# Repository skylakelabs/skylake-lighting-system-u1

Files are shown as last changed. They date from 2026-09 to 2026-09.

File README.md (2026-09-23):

# Skylake Lighting System for Snapmaker U1

Tested WLED integration for the Skylake LED Top Panel Kit. The stock U1 cavity-light control remains the master switch: off turns WLED off, and on loads WLED preset 1.

This README is the abbreviated procedure for users already comfortable with Fluidd and Klipper configuration. The complete hardware and beginner-focused walkthrough is maintained on the Skylake website.

> [!WARNING]
> This configuration transfers MCU pin `PE15` from the stock purifier to `skylake_24v`. Never let both objects own `PE15`. Back up `printer.cfg` and `moonraker.conf`, make no wiring changes while powered, and do not perform this work during a print.

## Files

| File | Purpose |
| --- | --- |
| [`skylake-wled.cfg`](skylake-wled.cfg) | Enables the top-cover 24 V rail and mirrors the cavity-light state to WLED. |
| [`skylake-moonraker.conf`](skylake-moonraker.conf) | Defines the WLED connection, preset, and 20-LED chain. |
| [`LEDTopPanel-SkylakeLabs-1.7.6.3mf`](models/LEDTopPanel-SkylakeLabs-1.7.6.3mf) | Prepared three-plate project with Snapmaker U1 slicer and support settings. |
| [`SnapmakerU1-LEDTopPanel1.7.6.stl`](models/SnapmakerU1-LEDTopPanel1.7.6.stl) | Raw model geometry for users who prefer to configure slicing manually. |

## Model files

For the recommended print setup, open the 3MF project in a compatible slicer and review its plate, material, and support settings before printing. Use the STL when importing the geometry into another slicer or creating a custom print profile.

Both model files are version **1.7.6** and are stored in the [`models`](models) folder.

## Advanced installation

1. On the U1 touchscreen, enable **Settings → Maintenance → Advanced Mode**. Open Fluidd and back up `printer.cfg` and `moonraker.conf`.
2. Upload `skylake-wled.cfg` and `skylake-moonraker.conf` beside the stock configuration files.
3. In `skylake-moonraker.conf`, replace the example `address` with the WLED controller's fixed IP address. Keep the supplied LED count:

   ```ini
   [wled skylake_lights]
   type: http
   address: 192.168.0.123
   initial_preset: 1
   chain_count: 20
   ```

4. In the stock `[purifier]` section of `printer.cfg`, comment out only the `PE15` assignment:

   ```ini
   [purifier]
   exhaust_pin: !PA8
   inner_pin: !PA9
   # power_enable_pin: PE15
   power_det_pin: PA7
   ```

5. Add this to `printer.cfg`, outside every other configuration section:

   ```ini
   [include skylake-wled.cfg]
   ```

6. Add this to `moonraker.conf`:

   ```ini
   [include skylake-moonraker.conf]
   ```

7. Power-cycle the printer. Confirm all four toolheads are detected, toggle the stock cavity light, verify all 20 LEDs, and test the official top-cover fans and controls. Do not use unattended printing if any stock function behaves unexpectedly.

## WLED setup

1. Power on the printer and join the `WLED-AP` Wi-Fi network using the default password `wled1234`.
2. Open `http://4.3.2.1/`, configure the controller for the local Wi-Fi network, and reconnect your device to that network.
3. In **WLED → Config → LED Preferences**, confirm the LED length is **20**.
4. Note the WLED controller's IP address, put it on the `address:` line in `skylake-moonraker.conf`, save, and restart Moonraker or reboot the printer.
5. Save the desired normal white-light configuration as WLED preset 1.

## Required check after every printer update

A Snapmaker firmware update may replace or remove configuration files. Before using Skylake after any printer update, verify all six items:

- `skylake-wled.cfg` still exists beside `printer.cfg`.
- `skylake-moonraker.conf` still exists beside `moonraker.conf`.
- `[include skylake-wled.cfg]` is still present in `printer.cfg`.
- `[include skylake-moonraker.conf]` is still present in `moonraker.conf`.
- The stock `[purifier]` line `power_enable_pin: PE15` remains commented out before the Skylake include is enabled.
- `skylake-moonraker.conf` still contains the correct WLED IP address and `chain_count: 20`.

Then power-cycle the printer and repeat the functional tests. Never enable `skylake-wled.cfg` while the stock purifier also owns `PE15`.

## Fast recovery

If Klipper does not return to Ready:

1. Remove or comment out `[include skylake-wled.cfg]` in `printer.cfg`.
2. Restore `power_enable_pin: PE15` in the stock `[purifier]` section.
3. Restart the printer.

If Moonraker fails separately, remove or comment out `[include skylake-moonraker.conf]` and restart Moonraker.

## Known log message

Because the stock purifier no longer owns a `power_enable_pin`, changing its fan speed may produce this non-fatal message:

```text
[purifier] power enable pin not exist!
```

The implementation logs the message and returns instead of raising a command error.

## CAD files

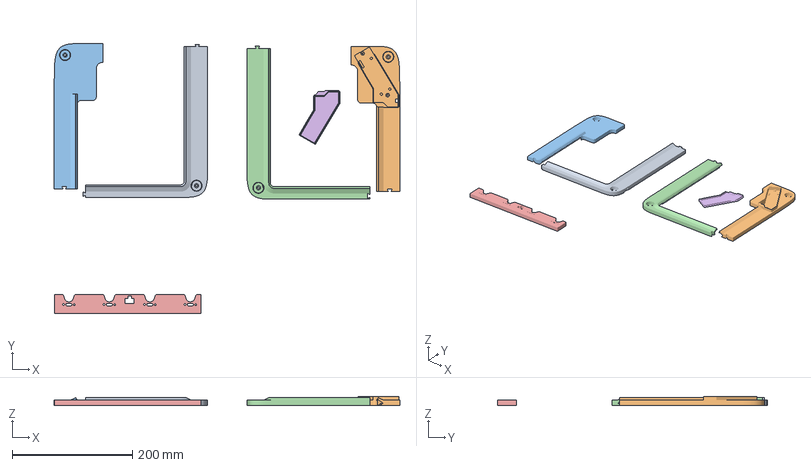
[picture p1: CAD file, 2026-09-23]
models/LEDTopPanel-SkylakeLabs-1.7.6.3mf
575.8 x 448.9 x 15.2 mm
SnapmakerU1-LEDTopPanel1.7.6.stl_1
SnapmakerU1-LEDTopPanel1.7.6.stl_2
SnapmakerU1-LEDTopPanel1.7.6.stl_3
SnapmakerU1-LEDTopPanel1.7.6.stl_4
SnapmakerU1-LEDTopPanel1.7.6.stl_5
SnapmakerU1-LEDTopPanel1.7.6.stl_6

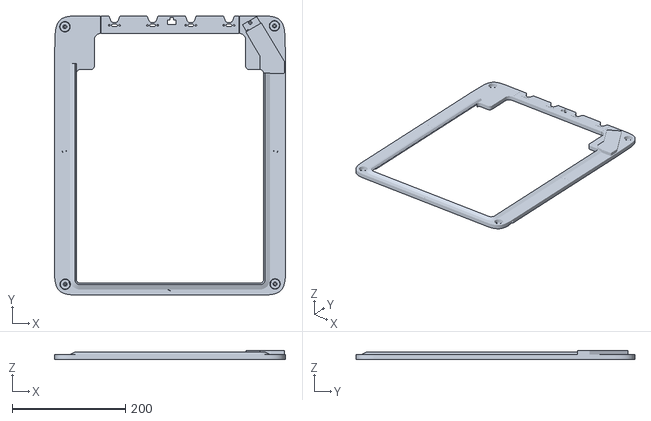
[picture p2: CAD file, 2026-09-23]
models/SnapmakerU1-LEDTopPanel1.7.6.stl
408.1 x 492.6 x 16.5

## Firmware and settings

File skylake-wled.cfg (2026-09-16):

# Skylake Lighting System
# Keeps the top-cover 24 V rail enabled and mirrors the Snapmaker U1
# cavity-light state to WLED.
#
# IMPORTANT: Comment out "power_enable_pin: PE15" in the stock [purifier]
# section before loading this file. PE15 must never have two owners.
#
# Power behavior:
# - PE15 is enabled when Klipper configures the MCU.
# - PE15 remains enabled while Klipper is operating.
# - PE15 uses a safe inactive shutdown value.
#
# Master behavior:
# - Cavity light OFF always turns WLED OFF.
# - Cavity light ON turns WLED ON with preset 1.
# - Calls WLED only when the cavity-light state changes.

[output_pin skylake_24v]
pin: PE15
value: 1
shutdown_value: 0

[gcode_macro _SKYLAKE_WLED_STATE]
variable_last_cavity_state: -1
gcode:


[delayed_gcode _SKYLAKE_WLED_WATCHER]
initial_duration: 2
gcode:
    {% set colors = printer["led cavity_led"].color_data %}
    {% set cavity_on = 1 if colors and colors[0][3]|float > 0 else 0 %}
    {% set last_cavity_state =
        printer["gcode_macro _SKYLAKE_WLED_STATE"].last_cavity_state|int
    %}

    {% if cavity_on != last_cavity_state %}
        {% if cavity_on == 1 %}
            {action_call_remote_method(
                "set_wled_state",
                strip="skylake_lights",
                state=True,
                preset=1
            )}
        {% else %}
            {action_call_remote_method(
                "set_wled_state",
                strip="skylake_lights",
                state=False
            )}
        {% endif %}

        SET_GCODE_VARIABLE MACRO=_SKYLAKE_WLED_STATE VARIABLE=last_cavity_state VALUE={cavity_on}
    {% endif %}

    UPDATE_DELAYED_GCODE ID=_SKYLAKE_WLED_WATCHER DURATION=1

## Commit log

2026-09-16 Add initial Snapmaker U1 lighting configuration
    [skylake-wled.cfg]
2026-09-16 Add installation guide and set LED count to 20
2026-09-23 Add LED Top Panel model files
    [LEDTopPanel-SkylakeLabs-1.7.6.3mf, SnapmakerU1-LEDTopPanel1.7.6.stl]
